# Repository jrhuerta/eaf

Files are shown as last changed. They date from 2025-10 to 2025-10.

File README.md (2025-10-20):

# MyFocuserPro2 EAF - EAF Bracket Compatible Telescope Focuser

A DIY electronic telescope focuser engineered for **heavy imaging trains** and designed to be physically compatible with standard EAF mounting brackets. Simply order the PCB from JLCPCB or PCBWay, solder a few components, 3D print the enclosure, and you'll have a robust focuser capable of handling substantial camera and filter wheel setups at a fraction of commercial prices.

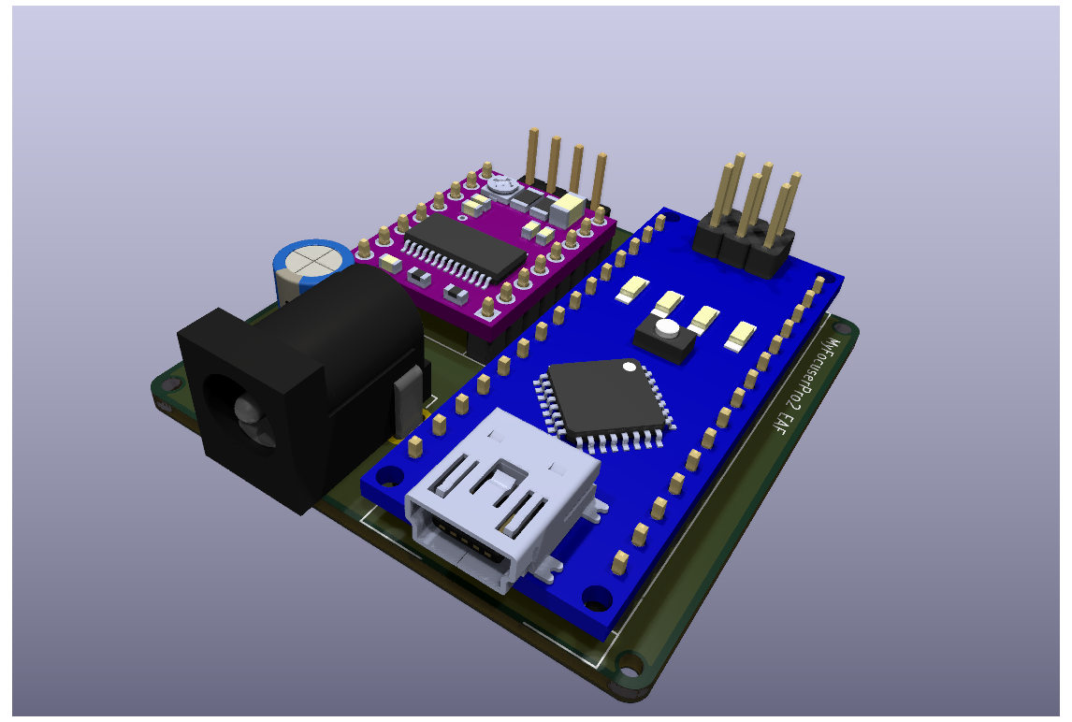
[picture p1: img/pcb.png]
PCB


  

## 🎯 Project Overview

This focuser is based on the MyFocuserPro2 project with modifications for standard EAF bracket compatibility. It uses a precision geared stepper motor, Arduino Nano microcontroller, and DRV8825 stepper driver, all integrated into a single compact enclosure that mounts directly to standard EAF brackets using the same bolt pattern.

**Perfect for astrophotographers** running heavy imaging setups with large cameras, filter wheels, and guide cameras - this focuser provides the torque and precision needed for reliable focusing under load.

### Key Features

- **Heavy Load Capable**: Engineered to handle substantial imaging trains with confidence
- **EAF Bracket Compatible**: Same mounting pattern and bolt spacing as standard EAF brackets
- **Simple DIY Build**: Order PCB → Solder components → Print enclosure → Done!
- **High Precision**: Uses 17hs13-0404S-PG27 geared stepper motor from StepperOnline
- **Arduino-Based**: Easy to program and modify with Arduino Nano
- **Cost-Effective**: ~$50-80 total cost vs $300+ for commercial alternatives
- **Production Ready**: Designed for easy ordering from JLCPCB/PCBWay

## 🛠️ Hardware Components

### Main Components

| Component | Part Number/Description | Quantity | Notes |
|---|---|---|---|
| **Stepper Motor** | 17hs13-0404S-PG27 | 1 | Geared stepper from StepperOnline |
| **Microcontroller** | Arduino Nano | 1 | Standard Arduino Nano board |
| **Motor Driver** | DRV8825 | 1 | Pololu-compatible stepper driver |
| **Capacitor** | 100µF Electrolytic | 1 | Power supply filtering |
| **Power Connector** | DC Barrel Jack | 1 | 12V power input |
| **Motor Connector** | 4-pin Header | 1 | Stepper motor connection |

### PCB Specifications

- **Design Tool**: KiCad 9.x
- **Board Size**: Compact form factor optimized for enclosure
- **Layers**: 2-layer PCB design
- **Manufacturing**: Optimized for JLCPCB and PCBWay production
- **Power**: 12V input
- **Assembly**: Only 6 components to solder by hand

## 📁 Repository Structure

```
├── README.md                           # This file
├── enclosure/                          # 3D Printable Parts
│   ├── eaf-body.stl                   # Main enclosure body
│   └── eaf-cover.stl                  # Enclosure cover/lid
├── myfocuserpro2-eaf/                  # KiCad Project Files
│   ├── myfocuserpro2-eaf.kicad_pro    # KiCad project file
│   ├── myfocuserpro2-eaf.kicad_sch    # Schematic design
│   ├── myfocuserpro2-eaf.kicad_pcb    # PCB layout
│   ├── models/                        # 3D Models for PCB
│   │   ├── Arduino Nano.STEP          # Arduino Nano 3D model
│   │   └── DRV8825 STEPPER MOTOR...   # DRV8825 3D model
│   └── production/                    # Manufacturing Files
│       ├── bom.csv                    # Bill of Materials
│       ├── positions.csv              # Component placement
│       ├── designators.csv            # Component designators
│       ├── netlist.ipc                # Netlist for assembly
│       └── myfocuserpro2-eaf.zip     # Gerber files
```

## 🔧 Assembly Instructions

### 1. Order PCB

**JLCPCB Ordering:**
1. Go to [JLCPCB.com](https://jlcpcb.com)
2. Upload the Gerber file: `myfocuserpro2-eaf/production/myfocuserpro2-eaf.zip`
3. Use default settings (2-layer, 1.6mm thickness)
4. Order quantity: 5 boards (minimum order)
5. Cost: ~$10-15 shipped

**PCBWay Ordering:**
1. Go to [PCBWay.com](https://pcbway.com)
2. Upload the same Gerber file
3. Use default settings
4. Order quantity: 5 boards (minimum order)
5. Cost: ~$15-20 shipped

### 2. Source Components

**Total component cost: ~$30-40**

Order these components (reference `production/bom.csv` for exact specifications):
- Arduino Nano (1x) - ~$8
- DRV8825 driver board (1x) - ~$5
- 100µF electrolytic capacitor (1x) - ~$1
- DC barrel jack connector (1x) - ~$2
- Pin headers 2.54mm pitch (1x set) - ~$3
- 17hs13-0404S-PG27 stepper motor - ~$25

### 3. PCB Assembly (15 minutes)

**Required tools:** Soldering iron, solder, flux (optional)

1. **Solder Arduino Nano**: Place and solder to A1 position
2. **Solder DRV8825**: Place and solder to A2 position  
3. **Solder Capacitor**: Install C1 (mind polarity - longer leg to +)
4. **Solder Connectors**: Install J1 (4-pin), J2 (barrel jack), J3 (3-pin)
5. **Clean and inspect**: Check for cold joints and bridges

*No SMD components - all through-hole for easy hand soldering!*

#### Assembly Photos
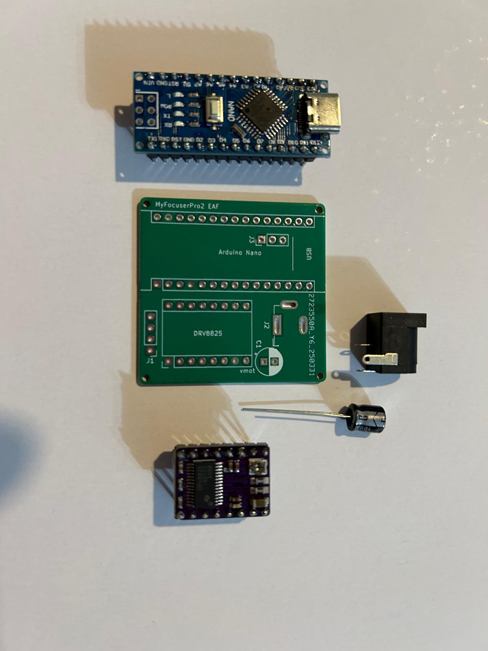
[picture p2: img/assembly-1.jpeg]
Assembly Step 1

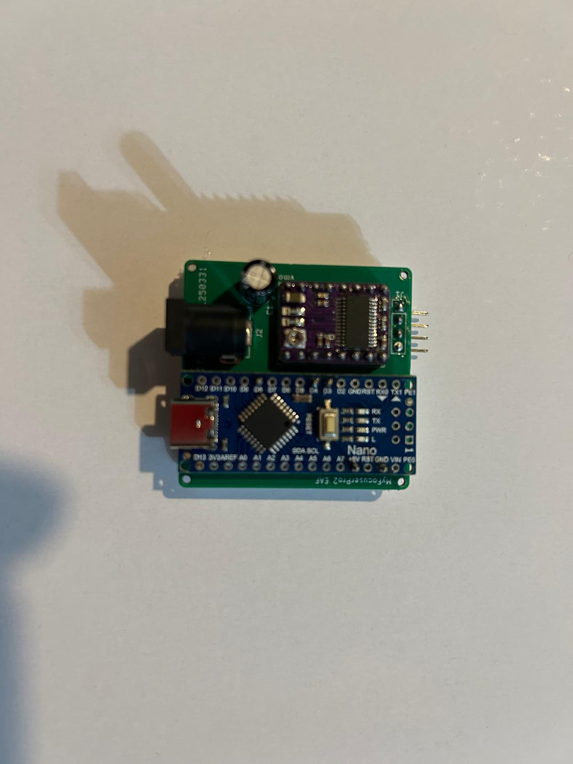
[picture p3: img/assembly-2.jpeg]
Assembly Step 2

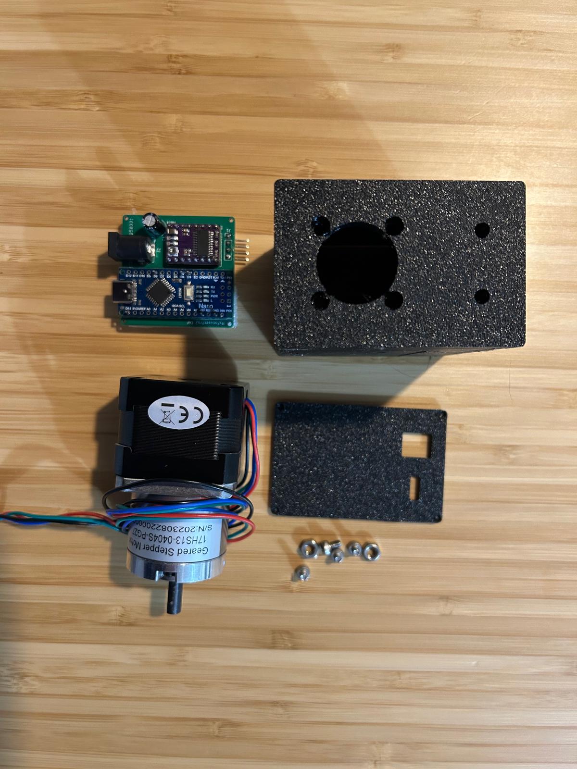
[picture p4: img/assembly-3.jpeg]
Assembly Step 3


### 4. 3D Printing (2-3 hours print time)

Print the enclosure parts from the `enclosure/` directory:

- **Files**: `eaf-body.stl` and `eaf-cover.stl`
- **Material**: PETG
- **Layer Height**: 0.2mm
- **Infill**: 20-30%
- **Print Speed**: Standard settings
- **Supports**: Minimal or none required
- **Cost**: ~$3-5 in filament

### 5. Motor Selection - Built for Heavy Loads

**Recommended Motor**: 17hs13-0404S-PG27 from StepperOnline

**Why this motor handles heavy imaging trains:**
- **27:1 Planetary Gearbox**: Massive torque multiplication for heavy loads
- **High Holding Torque**: Maintains position even with substantial weight
- **Smooth Operation**: Planetary gearing reduces vibration and backlash
- **Proven Design**: Successfully used in commercial focusers
- **Direct Mount**: No coupling required - direct attachment to focuser

**Load Capacity**: Easily handles imaging trains exceeding 3kg.

Tested with the following image train with consistent results. Commercial EAF units had issues handling this image train.

* Sharpstar ED 1x Coma corrector
* Off Axis Guider
* Wanderer Astro Rotator Mini V2
* 7x2" EFW (fully loaded)
* ASI2600MC

### 6. Final Assembly (10 minutes)

1. **Install PCB**: Place assembled PCB into printed enclosure body
2. **Connect Motor**: Stepper motor to J1 (4-pin header)
3. **Connect Power**: 12V power supply to J2 (barrel jack)
5. **Secure Cover**: Attach printed cover and test functionality
6. **Mount to Telescope**: Install using standard EAF bracket

**Total Build Time**: ~30 minutes active work + print time
**Total Cost**: ~$50 vs $300+ commercial focusers

#### Finished Product
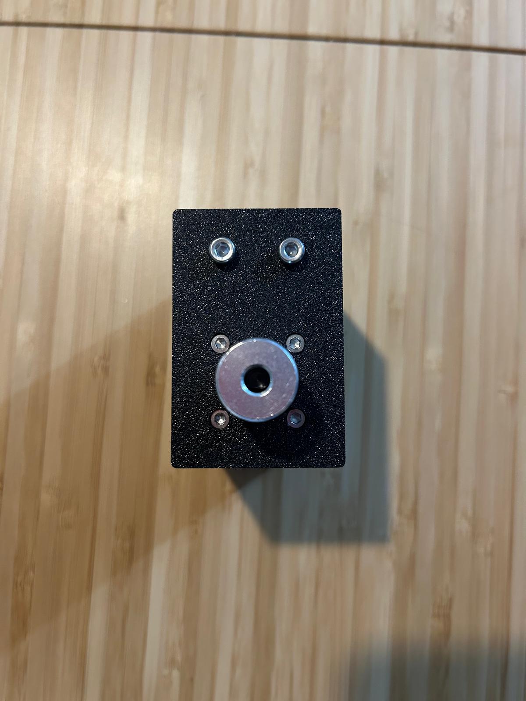
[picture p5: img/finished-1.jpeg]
Finished Focuser 1

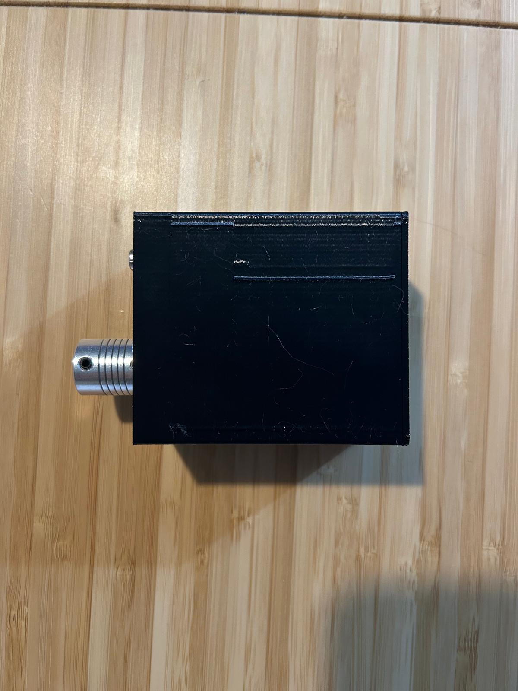
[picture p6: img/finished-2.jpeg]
Finished Focuser 2

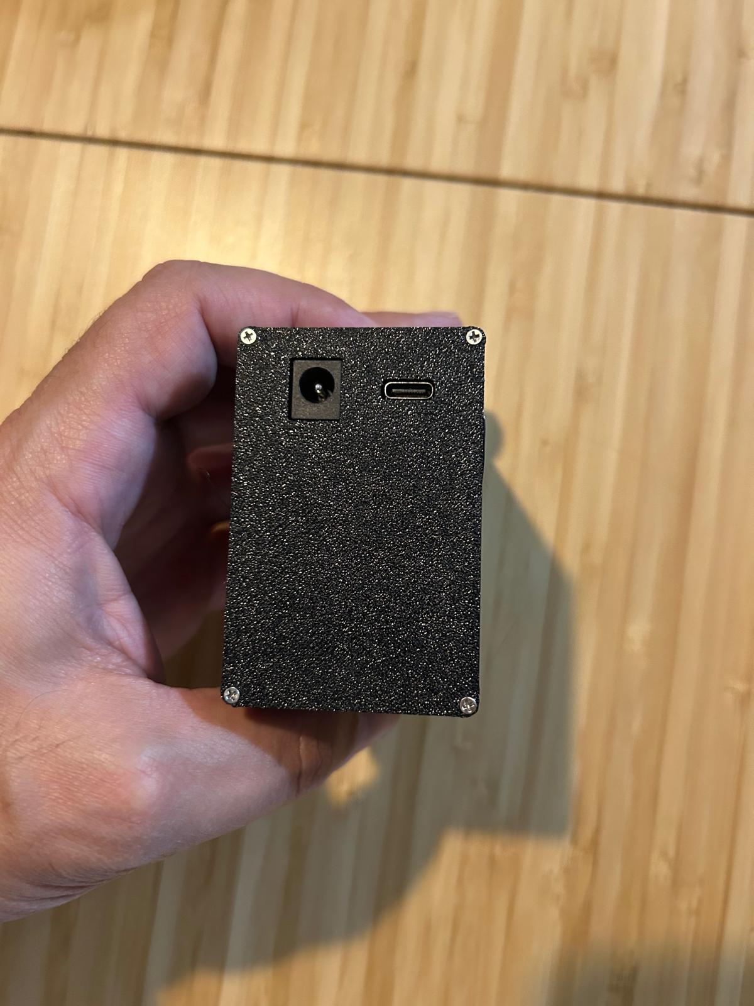
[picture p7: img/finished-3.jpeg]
Finished Focuser 3


## ⚡ Power Requirements

- **Input Voltage**: 12V DC
- **Current Draw**: < 500mA 
- **Power Connector**: Standard 2.1mm barrel jack (center positive)

## 🔌 Connections

### Motor Connection (J1)
```
Pin 1: A+    (Motor Phase A)
Pin 2: A-    (Motor Phase A)
Pin 3: B+    (Motor Phase B)
Pin 4: B-    (Motor Phase B)
```

### Control Interface (J3)
```
Pin 1: GND   (Ground)
Pin 2: IN    (Input/Button)
Pin 3: VCC   (3.3V/5V)
```

## 💻 Software

This hardware is designed to work with MyFocuserPro2 firmware or compatible Arduino-based focuser software. The Arduino Nano can be programmed via USB using the Arduino IDE.

**Recommended Software**:
- MyFocuserPro2 firmware
- ASCOM drivers for Windows
- INDI drivers for Linux

## 🔗 Compatibility

### Mechanical Compatibility
- **EAF Bracket**: Direct mounting compatibility with standard EAF bracket bolt pattern
- **Telescope Interfaces**: Standard focuser mounting patterns
- **Motor Coupling**: 17hs13-0404S-PG27 optimized design

### Software Compatibility
- **ASCOM**: Via MyFocuserPro2 drivers
- **INDI**: Linux astronomy software
- **Custom Software**: Arduino-programmable for custom implementations

## 📋 Bill of Materials (BOM)

| Designator | Component | Value/Part Number | Quantity |
|---|---|---|---|
| A1 | Arduino Nano | Standard Arduino Nano | 1 |
| A2 | DRV8825 | Stepper Motor Driver | 1 |
| C1 | Electrolytic Capacitor | 100µF | 1 |
| J1 | Pin Header | 4-pin, 2.54mm | 1 |
| J2 | Barrel Jack | DC Power Jack | 1 |

*Complete BOM with part numbers available in `myfocuserpro2-eaf/production/bom.csv`*

## 📐 Mechanical Specifications

- **Load Capacity**: 3-5kg+ imaging trains (6-11+ lbs)
- **Mounting**: Standard EAF bracket bolt pattern and center spacing
- **Enclosure Dimensions**: Optimized for EAF bracket compatibility
- **Weight**: Approximately 200-300g (depending on motor)
- **Motor Output**: Direct coupling to focuser mechanism
- **Backlash**: Minimal due to planetary gearbox design
- **Resolution**: Sub-micron focusing steps with geared motor

## 🚀 Getting Started - Quick Build Guide

**Total Cost: ~$50-80 | Build Time: ~30 minutes + 3 hours printing**

1. **Order PCB**: Upload Gerber files to JLCPCB or PCBWay (~$10-15)
2. **Buy Components**: Arduino Nano, DRV8825, motor, and basic parts (~$30-40)
3. **Order Motor**: 17hs13-0404S-PG27 from StepperOnline (~$25)
4. **3D Print**: Print enclosure parts (~$3-5 filament cost)
5. **Assemble**: 15 minutes soldering + 10 minutes final assembly
6. **Install Software**: Load MyFocuserPro2 firmware
7. **Mount and Focus**: Attach to telescope and enjoy precision focusing!

**Perfect for:**
- Heavy imaging setups (large cameras + filter wheels)
- Long focal length telescopes requiring precise focusing
- Astrophotographers wanting reliable, affordable automation
- Anyone tired of manual focusing with heavy equipment

## 🤝 Contributing

This is an open-source project. Contributions are welcome for:
- PCB improvements and optimizations
- Enclosure design enhancements
- Software compatibility updates
- Documentation improvements

## 📄 License

This project is open source. Please check individual file headers and project documentation for specific licensing terms.

## 🛠️ Support

For technical support and questions:
- Check existing issues and documentation
- Review MyFocuserPro2 project documentation
- Consult KiCad files for detailed design information

## 🔗 Related Projects

- **MyFocuserPro2**: Base project this design is derived from
- **StepperOnline**: Source for recommended geared stepper motor

---

**Note**: This project requires basic electronics assembly skills and access to PCB manufacturing services. Ensure you have appropriate tools and experience before beginning assembly.

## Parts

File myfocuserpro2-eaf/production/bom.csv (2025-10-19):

Designator | Footprint | Quantity | Value | LCSC Part #
A1 | Arduino_Nano | 1 | Arduino_Nano
A2 | Pololu_Breakout-16_15.2x20.3mm | 1 | DRV8825
C1 | CP_Radial_D6.3mm_P2.50mm | 1 | 100uF
J1 | PinHeader_1x04_P2.54mm_Vertical | 1 | Conn_01x04
J2 | BarrelJack_GCT_DCJ200-10-A_Horizontal | 1 | 12V
J3 | PinHeader_1x03_P2.54mm_Vertical | 1 | buttons

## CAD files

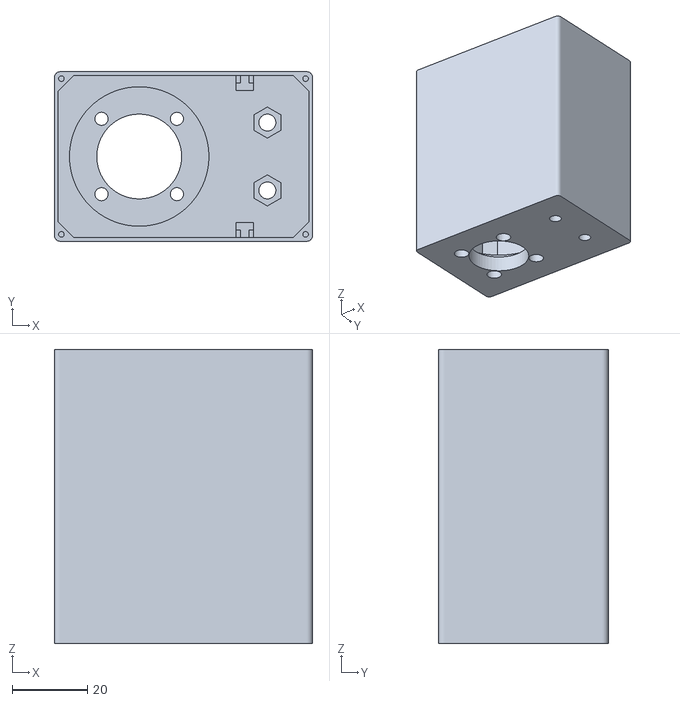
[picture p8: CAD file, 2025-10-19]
enclosure/eaf-body.stl
68.5 x 45.0 x 78.0

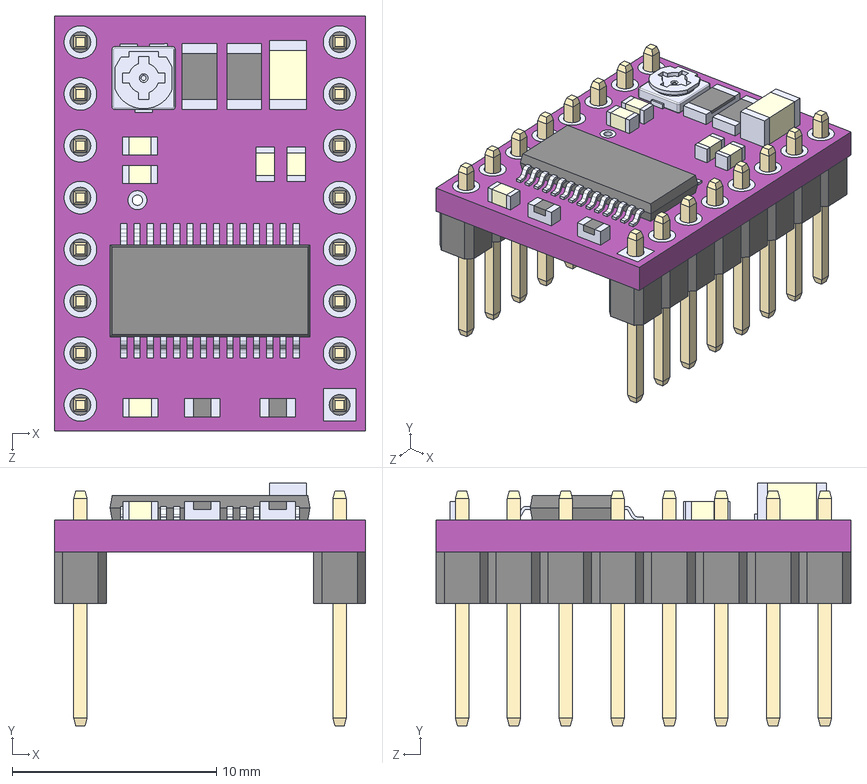
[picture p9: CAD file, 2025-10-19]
myfocuserpro2-eaf/models/DRV8825 STEPPER MOTOR DRIVER CARRIER--3DModel-STEP-1.STEP
15.2 x 11.9 x 20.3 mm

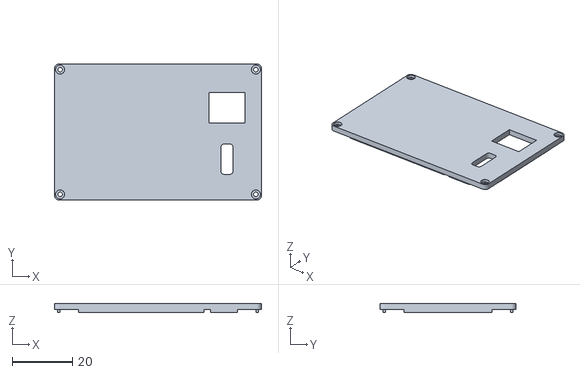
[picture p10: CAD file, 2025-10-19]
enclosure/eaf-cover.stl
68.5 x 45.0 x 3.00

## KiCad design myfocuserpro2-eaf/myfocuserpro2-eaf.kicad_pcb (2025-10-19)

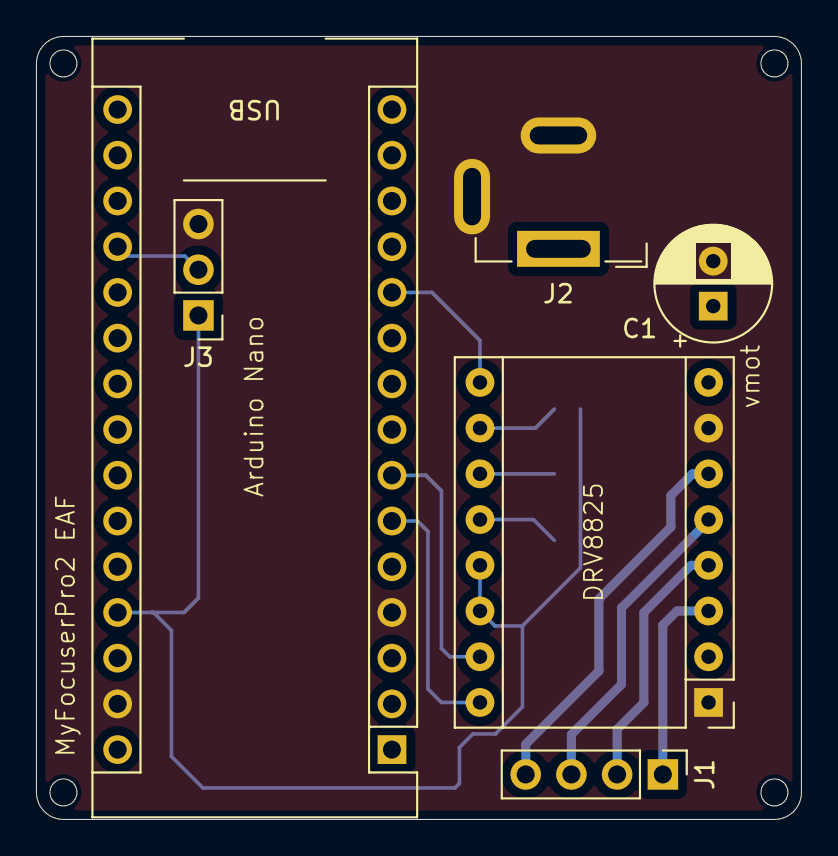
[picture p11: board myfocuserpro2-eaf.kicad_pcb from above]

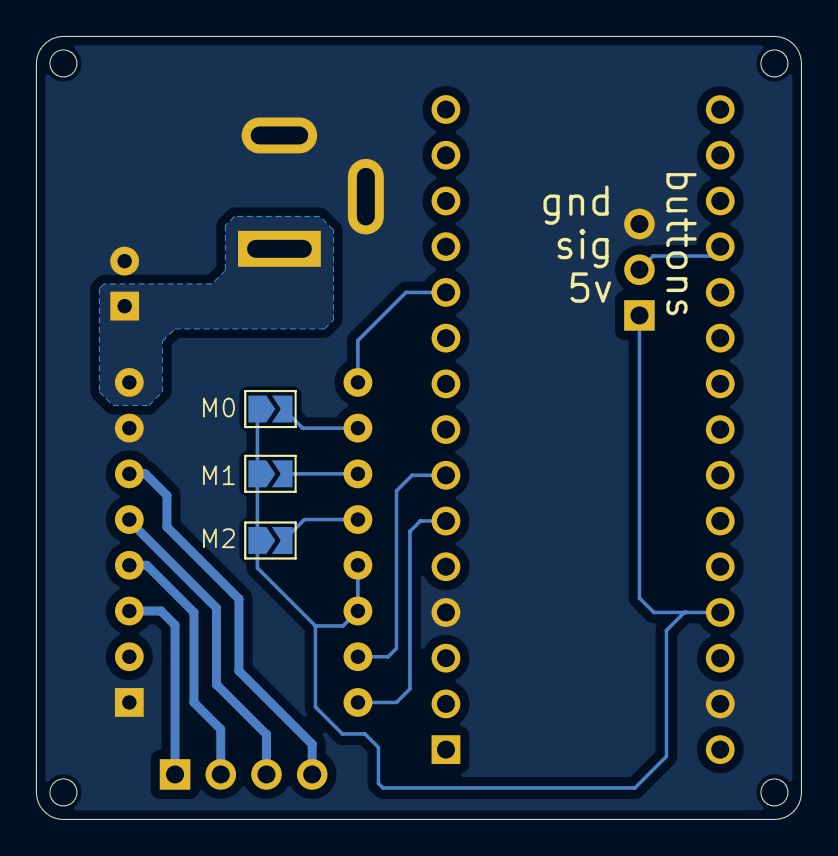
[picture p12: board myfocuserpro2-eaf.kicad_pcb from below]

Board: 2 copper layers, 42.5 x 43.5 mm, 13 parts (3 on the bottom side), 14 nets.

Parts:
A1: Arduino_Nano
A2: DRV8825; Pololu_Breakout-16_15.2x20.3mm
C1: 100uF; CP_Radial_D6.3mm_P2.50mm
H1, H2, H3, H4: MountingHole; MountingHole_1.5mm
J1: Conn_01x04; PinHeader_1x04_P2.54mm_Vertical
J2: 12V; BarrelJack_GCT_DCJ200-10-A_Horizontal
J3: buttons; PinHeader_1x03_P2.54mm_Vertical
JP1, JP2, JP3: SolderJumper_2_Open; SolderJumper-2_P1.3mm_Open_TrianglePad1.0x1.5mm

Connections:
+5V: A1.27 (+5V), A2.13 (~RST), A2.14 (~SLP), J3.1, JP1.1 (A), JP2.1 (A), JP3.1 (A)
/BUTTON: A1.19 (A0), J3.2
GND: A1.4 (GND), A1.29 (GND), A2.1 (GND), A2.7 (GND), C1.2, J2.2, J2.3, J3.3
unnamed: A1.6 (D3), A2.16 (DIR)
unnamed: A1.7 (D4), A2.15 (STEP)
unnamed: A1.11 (D8), A2.9 (~EN)
unnamed: A2.4 (A1), J1.2
unnamed: A2.3 (A2), J1.1
unnamed: A2.5 (B1), J1.3
unnamed: A2.6 (B2), J1.4
unnamed: A2.10 (M0), JP1.2 (B)
unnamed: A2.11 (M1), JP2.2 (B)
unnamed: A2.12 (M2), JP3.2 (B)
unnamed: A2.8 (VMOT), C1.1, J2.1

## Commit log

2025-10-19 Initial commit.
    [DRV8825 STEPPER MOTOR DRIVER CARRIER--3DModel-STEP-1.STEP, bom.csv, designators.csv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]
2025-10-20 Adding assembly and finished images.

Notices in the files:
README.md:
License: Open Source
